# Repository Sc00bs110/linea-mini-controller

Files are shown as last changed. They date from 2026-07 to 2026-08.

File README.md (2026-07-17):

# Linea Mini Controller

An open-source ESP32-S3 touchscreen controller for the La Marzocco Linea Mini
espresso machine.

<p align="center">
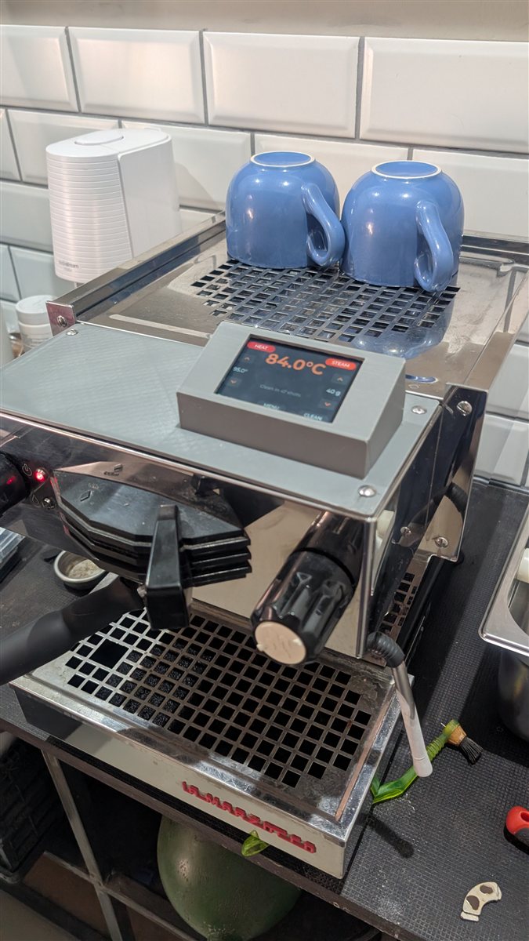
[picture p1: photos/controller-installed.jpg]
Controller in its 3D-printed housing, installed on top of a La Marzocco Linea Mini
  
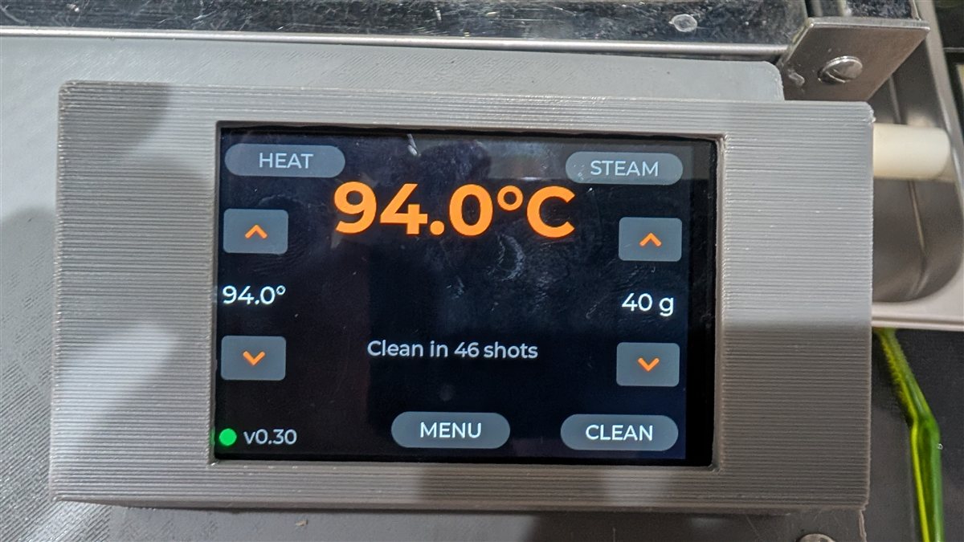
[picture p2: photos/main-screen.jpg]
Main screen close-up: boiler temperature, target temperature and brew weight, cleaning countdown, and HEAT/STEAM/MENU/CLEAN touch buttons
  
</p>

This project replaces the Linea Mini's stock control panel with a 3.5″ colour
touchscreen, adding brew-by-weight, shot timing, a cleaning-cycle reminder,
standby scheduling, Home Assistant integration, and over-the-air firmware
updates. It talks to the machine's own GICAR control board over the existing
CN11 connector using the same serial protocol the factory panel uses — **no
modification to the machine's electronics is required**, and the stock panel
can be refitted at any time.

It is a hobby project, built from a from-scratch reimplementation of the
GICAR protocol derived from sniffing the factory panel's traffic. It is not
affiliated with, endorsed by, or supported by La Marzocco.

## Features

- **Live machine display** — boiler temperature, target temperature, shot
  timer, and machine status on a 320×480 LVGL touch UI.
- **Brew-by-weight** — pairs with a Bluetooth scale (Felicita Arc or Bookoo
  Themis Ultra) and stops the shot automatically at a target weight, with a
  configurable pre-stop allowance to account for drip.
- **Shot counting that knows the difference** — pump runs shorter than
  20 seconds are treated as group-head flushes; only runs of 20 seconds or
  more count as shots.
- **Cleaning-cycle reminder** — counts down shots to the next backflush
  (interval set in the settings menu) and flags when a clean is due.
- **Standby scheduling** — daily wake and sleep times, timezone-aware.
- **Home Assistant integration** — MQTT discovery publishes boiler
  temperature, brewing state, steam and standby switches, shot counters, a
  firmware-update button, and online/availability sensors.
- **Shot history** — per-shot temperature samples logged to flash as a
  rolling window of recent shots.
- **Self-updating firmware** — the settings menu checks this repository's
  latest GitHub release and installs it from the screen: check → confirm →
  progress → reboot. A LAN-pull path (`tools/ota_pull.py`) supports fast
  iteration during development.

## Hardware

| Part | Details |
| --- | --- |
| MCU | DFRobot FireBeetle 2 ESP32-S3 (DFR0975) — ESP32-S3-WROOM-1-N16R8, 16 MB flash, 8 MB PSRAM |
| Display | DFRobot 3.5″ GDI touch display (DFR1092), 320×480, driven as an ILI9488 panel via LovyanGFX; GT911 capacitive touch over I²C |
| Machine link | UART to the machine's CN11 connector, carrying the GICAR protocol used by the stock panel |
| Scale (optional) | Felicita Arc or Bookoo Themis Ultra, via BLE |

**Wiring instructions — display, CN11 interface circuit, and power — are in
[docs/WIRING.md](docs/WIRING.md).** Deeper pin history lives in
`reference/lm_mini/` and the per-environment comments in `platformio.ini`.

An ESP32-C6 build environment (FireBeetle 2 ESP32-C6 / DFR1075) is also
defined and builds from the same source, but the S3 is the actively
maintained and deployed target.

> **CN11 wiring caveat:** the harness's TXD/RXD labels at the CN11 plug are
> crossed relative to what the wire colours and pull-up placement suggest.
> Trust decoded frames, not the labels — this cost real debugging time twice.
> If you are rewiring, verify with a loopback test at the plug before
> assuming which wire is which.

## Building from source

Requires [PlatformIO](https://platformio.org/).

```bash
cp include/secrets.h.example include/secrets.h
# edit include/secrets.h: WiFi credentials, MQTT broker, OTA password
pio run -e lm_controller_s3
```

`include/secrets.h` is gitignored and must never be committed. The
compiled-in WiFi and MQTT values only *seed* the device's flash storage on
first boot; after that the device uses its stored copies (which is how the
CI-built release binaries — compiled with blank secrets — keep your
connectivity across updates).

A pre-build hook regenerates `include/build_info.h` (git hash + build
timestamp) on every build. The human-facing version string (`FW_VERSION`,
e.g. `v0.30`) lives in `include/version.h` and is bumped on every deployed
release.

## Firmware updates

- **From the device** — Settings → "Firmware update" checks this
  repository's latest release over HTTPS and installs it if newer than the
  running version, with an on-screen confirmation step and progress readout.
- **From your LAN** — `python tools/ota_pull.py` serves a locally-built
  `firmware.bin` over HTTP and publishes an MQTT command telling the device
  to pull and flash it. This is the fast path when iterating without cutting
  a release.

Pushing a version tag (`v*`) builds the S3 firmware in GitHub Actions and
publishes a release with `firmware.bin` and a `version.json` manifest — see
`.github/workflows/release.yml`. Version history is in
[CHANGELOG.md](CHANGELOG.md).

## Repository layout

| Path | Contents |
| --- | --- |
| `src/` | Firmware: GICAR protocol driver, machine state, LVGL UI, BLE scale, MQTT/Home Assistant, OTA, shot log |
| `include/` | Headers, LVGL configuration, `version.h`, `secrets.h.example` |
| `tools/` | Build-info generator, LAN OTA server, espota fallback |
| `cad/` | OpenSCAD design and STLs for the machine-mounted display housing |
| `docs/` | Wiring instructions ([WIRING.md](docs/WIRING.md)) |
| `reference/` | Protocol captures and historical wiring notes |
| `.github/workflows/` | Tagged-release build pipeline |

## Safety

This project interfaces directly with a mains-powered heating appliance —
boiler, pump, and solenoids — via its OEM control board. Bugs in this
firmware could plausibly cause the machine to behave unexpectedly. Use at
your own risk. Not affiliated with, endorsed by, or supported by
La Marzocco.

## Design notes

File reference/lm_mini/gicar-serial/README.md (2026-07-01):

# gicar-serial — Ascaso Baby T Serial Protocol

Source: https://github.com/antondlr/gicar-serial

Reverse-engineered serial protocol for controlling an Ascaso Baby T espresso machine
via its Gicar control board and ESP32-based Bluetooth adapter.

## Key Findings

The machine uses a "Gicar 3d5 Maestro Deluxe Full Range '664' 3SSR" control board,
the same component found in professional multi-group machines. The Bluetooth daughter
board functions as a straightforward serial bridge, making the protocol accessible
to developers.

## Features

- Read and modify machine settings:
  - Power state
  - Coffee and steam temperatures
  - Shot doses and pre-infusion timing
  - Autotimer scheduling
  - Temperature display units
- Python CLI tools for reading state and adjusting parameters
- Supports direct Bluetooth connection, USB serial, or saved response files

## Relevance to La Marzocco Mini Project

Different machine (Ascaso Baby T) and different frame format (no Z/N prefix, 3-digit
address, 115200 baud) but same Gicar controller family. Key shared concepts:
- Temperature stored as value × 10
- Same checksum algorithm: sum(ASCII values, excl CS chars) mod 256
- Same register/offset addressing model

See docs/ for protocol details and memory map.
See python-poc/ for reference implementation.

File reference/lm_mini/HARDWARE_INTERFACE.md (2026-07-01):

# LilyGo T-Display-S3 — La Marzocco Mini Interface Design

## Overview

The LilyGo T-Display-S3 mounts at the front of the machine in a 3D-printed bracket.
A 4-wire cable runs from there to a small veroboard adapter mounted near CN11 inside
the machine. The adapter provides 5V power (from CN11 +12V via a buck converter) and
level-shifted serial (Gicar ASCII, 9600 8N1).

---

## CN11 Connector (machine main board)

| Pin | Signal  | Direction | Voltage |
|-----|---|---|---|
| 1 | GND | — | 0 V |
| 2 | RXD | Machine ← Gateway | 2.5V LVCMOS |
| 3 | TXD | Machine → Gateway | 2.5V LVCMOS |
| 4 | +12Vdc  | Machine → Gateway | 12 V |

> **Note:** CN11 is labelled "RS-232" but signals are empirically confirmed at
> 2.5V LVCMOS max. No level-shifter IC required.

---

## Interface Circuit

```
CN11                     Veroboard adapter              LilyGo T-Display-S3
────                     ─────────────────              ───────────────────
Pin 4 (+12V) ──────────► [XL7015 buck, adj→5V] ──────► 5V pin
Pin 1 (GND)  ──────────────────────────────────────── GND pin

                              R1 300Ω       R3 10kΩ
Pin 3 (TXD)  ─────────────────┤├──────┬─────┤├──── 3.3V
  machine transmits                   │
                                      └──────────► IO44 (UART1 RX)

                              R2 300Ω
Pin 2 (RXD)  ◄────────────────┤├───────────────── IO43 (UART1 TX)
  machine receives
```

**Firmware UART init:**
```cpp
Serial1.begin(9600, SERIAL_8N1, 44, 43, true);  // RX=IO44, TX=IO43, invert=true
```

---

## Bill of Materials

| Ref | Value | Description |
|-----|---|---|
| U1  | XL7015 module | DC-DC buck, adj 5–20V out, 0.8A, 5–80V in. Set trimmer to 5.0V before connecting. |
| R1  | 300Ω ¼W | Series resistor, CN11 TXD → IO44 |
| R2  | 300Ω ¼W | Series resistor, IO43 → CN11 RXD |
| R3  | 10kΩ ¼W | Pull-up, IO44 → 3.3V |
| — | 4-pin connector | CN11 mating connector (machine side) |
| — | 4-core cable | CN11 adapter → veroboard: +12V, GND, TXD, RXD |
| — | 4-core cable | Veroboard → LilyGo: 5V, GND, IO43, IO44 |

**Buck converter note:** The XL7015 module is rated 0.8A max. The LilyGo draws
≤500mA peak (ESP32-S3 WiFi active + display). Leave headroom by keeping the
display backlight below full brightness — cap it in firmware at ~80% (IO38 PWM).

---

## Component Notes

**R1, R2 — 300Ω series resistors**
- ESD and short-circuit protection on both signal lines
- At 9600 baud (104 µs/bit), RC time constant with ~10 pF GPIO capacitance ≈ 3 ns — negligible signal degradation
- Limits fault current to ≈10 mA if a line is shorted to GND or 3.3V

**R3 — 10kΩ pull-up on IO44**
- CN11 TXD idles high at 2.5V; ESP32-S3 VIH minimum ≈ 2.47V (0.75 × 3.3V)
- Pull-up raises the idle level to a solid 3.3V, giving reliable logic detection
- The machine's 2.5V driver easily overrides the pull-up when driving low (0V)
- Not needed on the TX line — IO43 outputs full 3.3V; machine input is tolerant

**Buck converter — initial setup**
1. Power the module from a bench supply at 12V (no load)
2. Measure output with a multimeter at the output pads
3. Adjust the trimmer pot until output reads exactly 5.0V
4. Re-measure under load (connect LilyGo, boot) — XL7015 output will sag slightly; re-trim if needed

---

## LilyGo T-Display-S3 Pin Connections

```
LilyGo T-Display-S3 (P1 header, bottom edge)
┌────────────────────────────────────┐
│  [1.9" ST7789V display]            │
│                                    │
│  ...  IO43  IO44  ...  5V  GND  ...│
│          │     │        │    │     │
│          │     │        │    └──── ◄── Veroboard GND
│          │     │        └───────── ◄── Buck 5V out
│          │     └────── R3(10kΩ)──► 3.3V
│          │             ◄── R1(300Ω) ◄── CN11 TXD (pin 3)
│          └──────────── R2(300Ω) ──► CN11 RXD (pin 2)
└────────────────────────────────────┘
```

IO17 and IO18 are used by the CST816S touch IC I2C bus (SCL/SDA) — do not use for serial.

---

## Physical Assembly

**Veroboard adapter** (small, ≤ 5×3 cm):
- XL7015 module soldered or mounted with header pins
- R1, R2, R3 inline between screw terminals or pin headers
- CN11 side: 4-pin header/screw terminal (+12V, GND, TXD, RXD)
- LilyGo side: 4-pin header/screw terminal (5V, GND, IO43, IO44)
- Mount near the existing daughterboard sub-enclosure

**Cable routing:**
- CN11 ribbon cable exits the main board sub-enclosure — splice or extend it
  to reach the veroboard adapter
- Run a 4-core cable from the veroboard adapter through the machine chassis to
  the front-mounted LilyGo; route away from mains/heating elements

**LilyGo front mount:**
- 3D-printed bracket at front of machine
- USB-C port accessible for firmware updates (or use OTA)
- IO14 button accessible or re-mapped to a front-panel button

---

## Verification Checklist

- [ ] Buck converter output trimmed to 5.00V at no load
- [ ] Buck converter output ≥ 4.85V with LilyGo powered and WiFi active
- [ ] LilyGo boots, display shows UI, WiFi connects
- [ ] `[gicar] frame` lines appear in serial monitor at 115200 baud
- [ ] Temperature readings visible on display (confirms Gicar RX working)
- [ ] Machine responds to a write command (confirms Gicar TX working)
- [ ] No heat on R1/R2/R3 after 30 min of operation

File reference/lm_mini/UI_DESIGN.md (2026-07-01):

# La Marzocco Mini Controller — UI Design

Display: LilyGo T-Display-S3, ST7789V 320×170 landscape (rotation=3, USB-left)  
Framework: LVGL 8.4 — dark theme, Montserrat fonts  
Input: CST816S capacitive touch + IO14 button (both active simultaneously)

---

## Color Palette

| Role | Hex | Usage |
|---|---|---|
| Background | `#000000` | All screens |
| Amber primary | `#D4891A` | Temperature, key values |
| Amber bright | `#F0A830` | Edit-mode values |
| Green | `#5CB85C` | Brew active, SHOT label |
| Orange | `#FF7043` | Steam active pill |
| White | `#FFFFFF` | Shot timer text, selected items |
| Grey mid | `#888888` | Status, secondary labels |
| Grey dim | `#555555` | Shots counter, hint text |
| Grey very dim | `#2A2A2A` | Hint overlays, invisible-until-lit |
| Blue highlight  | `#2878D8` | Selected settings row (20% opacity)|

---

## Typography

| Font | Size | Usage |
|---|---|---|
| Montserrat 48 | 48px | Temperature (main), elapsed time (timer)|
| Montserrat 32 | 32px | (reserved for future use) |
| Montserrat 24 | 24px | (reserved) |
| Montserrat 20 | 20px | BREWING label, SHOT label, timer temp |
| Montserrat 16 | 16px | Status, shots, settings items, hints |

---

## Screen 1 — Main

Default screen. Shows machine state at a glance.

```
┌────────────────────────────────────────────────────────────────┐ 320px
│                            ┌──────────────┐                    │
│                            │    STEAM     │  ← orange if on    │ 8px
│  93.5°C                    └──────────────┘                    │
│                                                                │ 85px (mid)
│  (amber M48)                   BREWING  ← green M20, hidden   │
│                                                                │
│                                0 shots  ← grey M16            │
│─────────────────────────────────────────────────────────────── │
│  192.168.1.113  |  Demo mode            ← grey M16            │ 148px
│  short=demo brew  long=menu  tap=settings  ← very dim         │ 164px
└────────────────────────────────────────────────────────────────┘ 170px
```

**Widgets:**
- `lbl_temp` — LEFT_MID (8, -12), M48, amber `#D4891A`
- `obj_steam` — TOP_RIGHT (-8, 8), 100×26, radius=13, bg dark → orange when active
  - `lbl_steam` — centered M16 inside pill
- `lbl_brew` — RIGHT_MID (-8, 8), M20, green, hidden when not brewing
- `lbl_shots` — RIGHT_MID (-8, 40), M16, dim grey
- `lbl_status` — BOTTOM_LEFT (8, -24), M16, grey — IP + machine state
- `lbl_hint` — BOTTOM_LEFT (8, -6), M16, very dim grey — controls hint

**Controls:**
| Input | Action |
|---|---|
| Touch (any area) | Open Settings screen |
| IO14 short press | Toggle 15s demo brew (when not connected) |
| IO14 long press  | Open Settings screen |

**Auto-transitions:**
- brew active → auto-switch to Timer screen (shot count incremented)

---

## Screen 2 — Shot Timer

Shown automatically when a brew starts. Returns to Main 3s after brew ends,
or immediately on tap.

```
┌────────────────────────────────────────────────────────────────┐
│                                                                │
│  28.5 s                          93.5°C   ← amber M20         │
│  (white M48)                                                   │
│                                  SHOT     ← green M20         │
│                                                                │
│                                         Shot #3  ← dim grey   │
└────────────────────────────────────────────────────────────────┘
```

**Widgets:**
- `lbl_shot_time` — LEFT_MID (8, -12), M48, white — `"28.5 s"` format
- `lbl_timer_temp` — RIGHT_MID (-8, -12), M20, amber — live temp
- `lbl_shot_label` — RIGHT_MID (-8, 16), M20, green, static text "SHOT"
- `lbl_timer_shots` — BOTTOM_RIGHT (-8, -6), M16, dim grey — "Shot #N"

**Controls:**
| Input | Action |
|---|---|
| Touch (any area) | Abort brew, return to Main immediately |
| IO14 (any press) | No action |

**Auto-transitions:**
- brew ends → stays on timer for 3s then auto-returns to Main

---

## Screen 3 — Settings

Entered from Main via long-press or tap. All 6 items fit within 170px.

```
┌────────────────────────────────────────────────────────────────┐ ← 26px header
│  SETTINGS       btn:short=next  long=select  tap=cycle  (dim) │
├────────────────────────────────────────────────────────────────┤
│ > Coffee temp                              93.5°C  ← selected │ 24px
│   Pre-infusion                               OFF              │ 24px
│   Steam                                      OFF              │ 24px
│   Auto-standby                               OFF              │ 24px
│   Clean cycle                                Run              │ 24px
│   Back                                                        │ 24px
└────────────────────────────────────────────────────────────────┘
```

Header: `#181818` bg, `lbl_settings_hdr` M20 grey left, hint M16 very dim right.

Each row (320×24): highlight = blue (#2878D8) at 20% opacity on selected row.
- Name label: LEFT_MID (4, 0), M16, grey → white when selected
- Value label: RIGHT_MID (-8, 0), M16, dim → amber when selected → `< val >` in bright amber when editing

**Settings items:**

| # | Name | Values | Step | Command sent on confirm |
|---|---|---|---|---|
| 0 | Coffee temp | 88.0–96.0°C | 0.5°C | `machine_set_temp()` |
| 1 | Pre-infusion  | OFF, 0.5–10.0 s | 0.5s | (TODO — register TBD) |
| 2 | Steam | ON / OFF | toggle  | `machine_set_steam()` |
| 3 | Auto-standby  | OFF, 15, 30, 60 min | cycle | (TODO — task #16) |
| 4 | Schedule | — (navigate) | — | opens Schedule List screen |
| 5 | Clean cycle | — (action) | — | opens Cleaning Cycle flow |
| 6 | Back | — (action) | — | `settings_save()` + main |

**Button controls:**
| Input | Action |
|---|---|
| Short press | Move `>` cursor to next item (wraps) |
| Long press (item) | Enter edit mode — value shows `< val >` |
| Short press (edit)| Cycle value one step |
| Long press (edit) | Confirm + save + exit edit mode |
| Long press (Back) | Save + return to Main |

**Touch controls:**
| Input | Action |
|---|---|
| Tap any value row | Immediately cycle value one step (no edit mode) |
| Tap Back row | Save + return to Main |
| Tap Clean row | Trigger clean cycle |

Both controls are live simultaneously — button and touch can be mixed freely.

---

## Navigation Flow

```
                  ┌─────────┐
      ┌──touch────►         ◄──────brew ends (3s)──┐
      │  long btn ► MAIN    │                       │
      │           │         ├────brew starts───────►TIMER
      │           └────┬────┘                       │  │
      │                │ touch / long btn            │  touch
      │                ▼                             │  (abort)
      │           SETTINGS                          │  │
      │           │       │                         │  │
      └───────────┘       └─────────────────────────┘  │
       tap Back /                                       │
       long btn on Back                                 │
                                         ◄─────────────┘
```

---

## Cleaning Cycle Flow (multi-screen guided procedure)

Entered from Settings → "Clean cycle". Seven steps, cannot be skipped.

### Step 1 — Confirmation
```
┌────────────────────────────────────────────────────────────────┐
│  CLEANING CYCLE                                                │
│                                                                │
│  Takes approx. 2 minutes.                                      │
│  Insert blind basket with cleaning powder                      │
│  and lock portafilter in place.                               │
│                                                                │
│          [Cancel]              [Start Cleaning]                │
└────────────────────────────────────────────────────────────────┘
```

### Step 2 — Paddle Prompt (cleaning)
After "Start Cleaning" is tapped: send Gicar `W00E1000182` (cleaning command).
```
┌────────────────────────────────────────────────────────────────┐
│  CLEANING CYCLE                                                │
│                                                                │
│  Move paddle to start cleaning                                 │
│                                                                │
│                    15                                          │
│              (countdown seconds)                               │
│                                                                │
│  ────────────────────────── (progress bar)                     │
└────────────────────────────────────────────────────────────────┘
```
- Monitor Gicar state bytes [28..37] for brew-active (paddle moved)
- Paddle detected → proceed to Step 3
- 15s elapsed, no paddle → show "Cleaning cancelled" + return to settings

### Step 3 — Cleaning in Progress
```
┌────────────────────────────────────────────────────────────────┐
│  CLEANING CYCLE                                                │
│                                                                │
│  Cleaning in progress...                                       │
│                                                                │
│  Cycle  3 / 10      ████████░░░░░░░░░░░░  30s                 │
│  (3 seconds ON, 3 seconds OFF per cycle)                       │
│                                                                │
└────────────────────────────────────────────────────────────────┘
```
- 10 cycles × (3s ON + 3s OFF) = ~60 seconds total
- Show cycle counter if detectable from Gicar state; otherwise show elapsed timer
- State bytes return to normal → proceed to Step 4

### Step 4 — Rinse Preparation
```
┌────────────────────────────────────────────────────────────────┐
│  CLEANING CYCLE                                                │
│                                                                │
│  Cleaning complete.                                            │
│                                                                │
│  Remove portafilter, rinse it thoroughly,                      │
│  then lock it back in place.                                   │
│                                                                │
│          [Cancel]              [Start Rinse]                   │
└────────────────────────────────────────────────────────────────┘
```

### Step 5 — Paddle Prompt (rinse)
After "Start Rinse" tapped: send `W00E1000182` again.
Same countdown and paddle-detection logic as Step 2.

### Step 6 — Rinse in Progress
Same display as Step 3, text reads "Rinsing...".  
10 cycles × (3s ON + 3s OFF).

### Step 7 — Complete
```
┌────────────────────────────────────────────────────────────────┐
│                                                                │
│                   Cleaning Complete                            │
│                                                                │
│              30 May 2026  14:23                                │
│                                                                │
│              (returns to settings in 3s)                       │
│                                                                │
└────────────────────────────────────────────────────────────────┘
```
- Record Unix timestamp to NVS: namespace `"maintenance"`, key `"last_clean_ts"`
- Display formatted date/time
- Auto-return to settings after 3 seconds

### Gicar Command
- `W00E1000182` (register 0x00E1, value 0x82, checksum 58) — confirmed via logic analyser
- Same command used for both cleaning and rinse cycles
- Machine requires user paddle movement to actually start the pump cycle

### NVS
- Namespace: `"maintenance"`, key: `"last_clean_ts"` (uint32, Unix epoch)
- Exposed in Home Assistant as sensor `last_cleaning` (ISO datetime string)

---

## Future Screens (planned)

### Screen 4 — Shot Detail (task #21)
Shows after a brew completes. Displays: shot time, yield (grams, from BLE scale),
ratio (dose:yield), temperature profile. Tap to dismiss.

### Screen 5 — Schedule (task #16)
Weekly on/off schedule editor. Grid of days × time slots.
Navigation: swipe left/right for days, tap to toggle time slots.

### Screen 6 — Scale / Brew-by-Weight Timer (tasks #19, #20, #21)

Scale: **Felicita Arc** (BLE). Replaces plain shot timer when scale is connected.

```
┌────────────────────────────────────────────────────────────────┐
│  28.5 s          ████████████░░░░░  36.2 → 40g   93.5°C       │
│  (M32, white)    (weight progress bar, green)     (M20, amber) │
│                                                                │
│  Shot #3                           1 : 2.3  (dose:yield ratio)│
└────────────────────────────────────────────────────────────────┘
```

**Auto-stop:** when live weight reaches `(target - offset)`, send brew-stop
command (`W80000001` — verify empirically, task #17). The offset compensates
for liquid still dripping after pump stops.

**Settings additions** (in settings menu):
- Brew target weight: 20–60g, step 1g (default 36g)
- Pre-stop offset: 0–8g, step 0.5g (default 3g) — stop at `target - offset`
- Scale: connect / disconnect / show status

---

## BLE Scale Integration — Architecture & Plan (tasks #19, #20, #21, #22)

**Scales on order:** Felicita Arc + Bookoo Themis Ultra  
Both must be supported simultaneously. Auto-detect on BLE scan — connect to whichever
is found first (or whichever is in range). No user configuration required.

---

### Firmware Architecture — Abstract Scale Driver

Both scales are wrapped behind a common interface so brew-by-weight, the shot
timer screen, and HA reporting never need to know which scale is connected:

```cpp
// src/scale.h

enum ScaleModel { SCALE_NONE, SCALE_FELICITA_ARC, SCALE_BOOKOO_THEMIS };

struct ScaleState {
    ScaleModel model;
    bool       connected;
    float      weight_g;   // live reading, grams
    bool       stable;     // weight stable (not changing rapidly)
};

extern ScaleState scale;

void  scale_init();                // start BLE scan task
void  scale_tare();                // send tare command to active scale
float scale_weight();              // current weight in grams (0.0 if disconnected)
bool  scale_connected();
const char* scale_name();          // "Felicita Arc" / "Bookoo Themis Ultra" / "—"
```

Internal: BLE task on core 0 scans for both device name prefixes, connects to the
first found, dispatches notifications to the correct parser, populates `scale`.
On disconnect, resumes scanning.

---

### BLE Protocol — Felicita Arc

| Item | Value |
|---|---|
| Device name prefix | `"FELICITA"` |
| Service UUID | `0xFFE0` |
| Notify characteristic | `0xFFE1` |
| Packet format | 10 bytes: `[cmd][weight_hi][weight_lo][sign][unit][...]` |
| Weight | `(byte[1] << 8 \| byte[2]) / 10.0` g; negative if `byte[3] == 1` |
| Update rate | ~10 Hz |

> Verify UUIDs and packet layout with **nRF Connect** before coding — Arc format
> differs slightly from older Felicita models.

---

### BLE Protocol — Bookoo Themis Ultra

| Item | Value |
|---|---|
| Device name prefix | `"Bookoo"` or `"BOOKOO"` |
| Service UUID | **TBD — scan with nRF Connect** |
| Notify characteristic | **TBD** |
| Packet format | **TBD** |
| Update rate | ~10 Hz (typical for espresso scales) |

> The Bookoo Themis Ultra is a newer device and its BLE protocol is less documented
> publicly. Scan with nRF Connect to capture the service/characteristic UUIDs and
> record a few notification payloads during weighing. This is needed before the
> Bookoo driver can be written.

---

### Brew-by-Weight Auto-Stop

```
During active brew, every 100 ms:
  w = scale_weight()
  if (scale_connected() && w >= (brew_target_g - prestop_offset_g)):
      gicar_write(0x8000, &stop_val, 1)   // brew stop — verify task #17
      record yield = w + drip_estimate
      mark shot as weight-stopped
      stop checking until next brew
```

**Pre-stop offset** (lag compensation):
- Espresso drips 2–4s after pump stops, adding 3–5g
- Default: 3g offset — stop pump at `target − 3g`, yield reaches ~target
- User-adjustable 0–8g in settings

---

### Shot Timer Screen — With Scale Active

```
┌────────────────────────────────────────────────────────────────┐
│  28.5 s                                            93.5°C      │
│                                                                │
│          36.2 g  ████████████████░░░░  / 40 g                 │
│          (M48 green)      (progress bar)                       │
│                                                                │
│  Shot #3                                    ratio  1 : 2.4    │
└────────────────────────────────────────────────────────────────┘
```

Without scale connected — falls back to plain elapsed timer (existing behaviour).

### Main Screen — Scale Status (right panel, below shot counter)
- Scale connected: `"36.2 g"` dim green M16
- Scanning: `"Scale..."` very dim grey M16
- Offline after timeout: nothing shown (no clutter)

---

### Settings Additions

| Item | Values | Default |
|---|---|---|
| Brew weight | 20–60 g, step 1 g | 36 g |
| Pre-stop offset | 0.0–8.0 g, step 0.5 g | 3.0 g |
| Scale status | display-only: name + RSSI or "Scanning..." | — |

---

### Home Assistant Entities (task #22)

| Entity | Type | Notes |
|---|---|---|
| `sensor.lm_scale_weight` | g | Live reading during shot |
| `sensor.lm_last_yield` | g | Yield of last completed shot |
| `sensor.lm_last_ratio` | — | Dose:yield (requires dose input) |
| `number.lm_brew_target` | g | Target brew weight |
| `number.lm_prestop_offset` | g | Pre-stop offset |
| `binary_sensor.lm_scale_connected` | — | BLE connection state |
| `sensor.lm_scale_model` | string | "Felicita Arc" / "Bookoo Themis Ultra" |

---

### Adaptive Pre-Stop Offset Algorithm

**Background — existing La Marzocco firmware:**
The gateway binary contains a `GicarAcaiaScaleMachine` class confirming scale-based
brew-stop. The NVS keys found (`scale-nm0`, `scale-nm1`, `scale-ack`) are scale
identification only — no adaptive offset keys (`scale-offset`, `scale-last-yield`,
`scale-learning-rate` etc.) were found. It is therefore **unknown** whether the
original firmware had adaptive learning; the evidence leans against it but is not
conclusive.

**Our implementation plan — adaptive pre-stop offset:**

After each completed shot where a scale was connected, record the final yield weight
(scale reading 5–10 seconds after pump stops, once dripping has slowed) and adjust
the stored offset using an exponential moving average:

```
error      = actual_yield_g - brew_target_g   // + means overshot, − means undershot
new_offset = old_offset + (error × 0.4)       // learning rate 0.4 → converges in ~4 shots
```

- Learning rate 0.4: corrects 40% of the error per shot — converges in 3–4 shots
  without overshooting
- Clamp `new_offset` to [0.0, 8.0] — safety bounds, same as manual setting
- Only update when `|error| > 0.5g` — ignore noise within half a gram
- Store in NVS (namespace `"scale"`, key `"offset"`) — survives power cycles
- Per-target tuning: offset at 36g target differs from 40g; optionally store as
  `"off_36"`, `"off_40"`, etc. (round to nearest gram) — implement if simple offset
  proves insufficiently accurate across different target weights

**Implementation order:**
1. Implement fixed offset first (done)
2. Add final-yield measurement once real scale arrives (read weight ~8s after brew ends)
3. Add NVS offset storage as part of task #15
4. Add adaptive update logic — ~20 lines, straightforward once NVS is in place

**Verification:** pull 5 shots with a consistent dose, record actual yield each time,
confirm the offset converges. If it oscillates, reduce learning rate to 0.25.

---

### Open Questions Before Coding Scale Drivers

1. **Bookoo Themis Ultra BLE:** scan with nRF Connect, record service UUID, char UUID, and 3–4 notification payloads at known weights (e.g. 10g, 20g, 30g) to reverse the encoding.
2. **Felicita Arc packet format:** confirm byte layout matches above — Arc may differ from Felicita Parallel/Brew models.
3. **Tare behaviour:** does each scale auto-tare on stable zero, or does firmware need to send an explicit tare command? Check nRF Connect for write characteristics.
4. **Brew-stop command:** verify `W80000001` empirically (task #17) before enabling auto-stop.
5. **Simultaneous scan:** confirm ESP32-S3 BLE stack handles scanning while a connection is already active (needed if user has both scales on the bench).

---

### Home Assistant integration (task #14)
No dedicated screen. HA controls are reflected in the settings screen
(same values, synced via MQTT). A small "HA" icon in the status line
indicates cloud sync active.

---

## Touch Coordinate Mapping

CST816S native: portrait X∈[0,169], Y∈[0,319]  
Display rotation=3 (landscape, USB-left) mapping:

```
display_x = SCREEN_W - 1 - raw_y   (319 - raw_y)
display_y = raw_x
```

If tap position appears mirrored, swap to Option B in `touch.cpp`:
```
display_x = raw_y
display_y = SCREEN_H - 1 - raw_x
```

---

## Pin Summary

| GPIO | Function | Notes |
|---|---|---|
| 43 | Gicar UART1 TX | CN11 → machine RXD, via 300Ω |
| 44 | Gicar UART1 RX | CN11 → machine TXD, 300Ω+10kΩ PU |
| 17 | Touch I2C SCL | CST816S on T-Display-S3 |
| 18 | Touch I2C SDA | CST816S on T-Display-S3 |
| 21 | Touch RST | Active-low reset |
| 16 | Touch INT | Interrupt (polled, not used) |
| 14 | IO14 button | Active-low, BUTTON_2 |
| 15 | LCD power enable | Must be HIGH before TFT init |
| 38 | Backlight | TFT_BL, driven HIGH |

Display parallel bus: D0-D7 = IO39-48, WR=IO8, RD=IO9, DC=IO7, CS=IO6, RST=IO5

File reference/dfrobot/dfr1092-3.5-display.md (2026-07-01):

# DFRobot 3.5" 480x320 IPS Capacitive Touch Screen (DFR1092)

Source (primary): https://wiki.dfrobot.com/dfr1092/
Also cross-checked against: https://wiki.dfrobot.com/SKU_DFR1092_3.5%22%20480%C3%97320%20IPS%20Capacitive%20Touch%20Screen
Product/store page: https://www.dfrobot.com/product-3025.html
Datasheet PDF (linked from wiki): https://dfimg.dfrobot.com/wiki/23471/DFR1092_480-320-ips-screen_datasheet_1.0.pdf
Schematic PDF (linked from wiki): https://dfimg.dfrobot.com/wiki/23471/DFR1092_480-320-ips-screen_schematics_1.0.pdf
Library (named on wiki as compatible): https://github.com/DFRobot/DFRobot_GDL

Retrieved: 2026-07-01

## HEADLINE FINDING — Driver IC is ST7365P, NOT ILI9488

**The prior iteration's assumption that this display uses an ILI9488 driver is WRONG.** The datasheet PDF that DFRobot itself links from the DFR1092 wiki page (`DFR1092_480-320-ips-screen_datasheet_1.0.pdf`) is, verbatim, the **Sitronix ST7365P** datasheet:

> "ST7365P — 320RGB x 480 dot 16.7M Color with Frame Memory — Single-Chip TFT Controller/Driver — Datasheet ... © 2013 Sitronix Technology Corporation."

This was confirmed by downloading the PDF directly and extracting its text (not just trusting a page summary) — the title page, part number, and section headers throughout the 14,700+ line document all say ST7365P/Sitronix. The panel resolution quoted in the datasheet (320 x 480) matches the DFR1092's native panel resolution exactly (DFRobot's own product description says *"It features a 320×480 IPS panel for 178° distortion-free full viewing"* — the "480×320" in the SKU/marketing name is the landscape-rotated figure).

Corroborating evidence:
- DFRobot's own `DFRobot_GDL` library (the library named as compatible with this display on the wiki) ships a driver class literally named `DFRobot_ST7365P_320x480_HW_SPI` (and a `..._DMA_SPI` DMA variant) — an exact resolution match for this panel — alongside separate classes for ILI9341/ILI9488/ST7789/ST7735S/ST7789/SSD1306 that do NOT match this panel's native resolution.
- **Likely source of the original ILI9488 assumption**: DFRobot sells a different, older, visually similar product — **DFR0669** ("Fermion: 3.5" 480x320 TFT LCD Capacitive Touchscreen with MicroSD Card Slot (Breakout)") — which genuinely IS ILI9488-driven, has the same 3.5"/480x320 spec, but uses a plain pin-header breakout (no GDI connector) and is a completely separate SKU. DFR0669 appears as a "related product" recommendation embedded in the DFR1092 wiki page's own page data, which is almost certainly what caused the mix-up. **Do not use ILI9488 init code, MADCTL values, or gamma tables for the DFR1092 — use ST7365P.**

## SKU and Physical Specs

| Parameter | Value |
|---|---|
| SKU | **DFR1092** |
| Screen size | 3.5 inches |
| Native panel resolution | 320 x 480 (portrait, per panel datasheet) — marketed as **480 x 320 (HVGA)** landscape |
| Panel type | IPS |
| Viewing angle | 178° (full view) |
| Brightness | 300 cd/m² |
| Contrast ratio | 800:1 |
| Surface treatment | Anti-fingerprint (AF) coating |
| Production process | Optical full bonding (reduces reflection, keeps out dust/moisture) |
| Effective display area | 48.96 x 73.94 mm |
| Overall dimensions | 95.0 x 54.5 x 5.7 mm |
| Mounting hole diameter | 2.0 mm |
| Mounting hole spacing | 90 x 50 mm |
| Weight | 62.6 g (with packaging) |
| Storage expansion | Built-in Micro SD card slot |

## Display Driver IC — CONFIRMED

**ST7365P** (Sitronix), a single-chip TFT controller/driver with on-chip frame memory, supporting 16.7M colors, native 320RGB x 480 dot panel. Supports both 3-line and 4-line SPI serial interface modes (datasheet sections 8.4.1 "3-Line Interface" and 8.4.2 "4-Line Interface"). The DFR1092 board is wired for **4-line SPI** (separate D/C line broken out, per the pinout below).

## Interface Type

- **SPI** (4-wire: SCLK, MOSI, MISO, CS + separate D/C and RST lines — i.e. the common "4-line" TFT SPI convention with 6 total control signals: SCK/MOSI/MISO/CS/DC/RST)
- Not parallel/RGB — this is a serial-only interface.
- Two physical connector options on the board:
  1. **GDI (Gravity Display Interface)** — DFRobot-proprietary 18-pin FPC connector, solder-free, single-cable, designed to plug directly into FireBeetle 2 boards (including the ESP32-C6 V1.2 in this project).
  2. **Standard 2.54 mm pin header** — 14 pins, for use with any generic MCU/Arduino via jumper wires.

## Touch Controller

- **Type**: Capacitive
- **Touch points**: 5-point multi-touch
- **Interface**: **I2C** — confirmed directly from the schematic (net labels `CTP_SCL`, `CTP_SDA`, `CTP_INT`, `CTP_RST` on the touch-panel FPC connector; also exposed as `SCL`/`SDA`/`INT`/`TP_R`(reset) on the 2.54 mm header and `SCL`/`SDA`/`INT`/`TCS` on the GDI connector).
- **Exact touch IC part number: NOT confirmed by a primary DFRobot source.** The wiki page, product page, datasheet, and the single-page schematic available from DFRobot all stop short of naming it (the schematic only shows a connector out to a separate touch-panel FPC/module; the touch chip itself lives on that module and isn't itemized in the documents DFRobot publishes for this SKU).
- Since the interface is I2C (not SPI), the touch IC is **not** the XPT2046 (SPI, resistive, single-touch) that `DFRobot_GDL` also supports. Of the touch drivers the library ships (`XPT2046`, `GT911`, `GT5688`), the I2C capacitive candidates are **GT911** or **GT5688** (both Goodix-family, both I2C, both multi-touch capable).
- A secondary (non-DFRobot-sourced, AI-search-synthesized) result claimed the DFR1092 specifically uses **GT911 at I2C address 0x5D**. This could not be traced to an actual DFRobot document, datasheet, or schematic text and should be treated as an **unverified lead, not a confirmed fact** — it may simply reflect GT911 being the generic, most common chip of its class rather than a DFR1092-specific citation. GT911 is the leading candidate on general-plausibility grounds (I2C, 5-point capacitive, extremely common in this display-size class, and already supported by DFRobot's own GDL library), but treat it as unconfirmed until verified against the physical unit's chip marking or direct DFRobot support confirmation.

## GDI Connector Pinout (18-pin FPC)

Order as documented on the wiki (pin 1 first):

| Pin # | FPC Label | Function |
|---|---|---|
| 1 | VCC | Power, 3.3 V |
| 2 | LCD_BL | Backlight control |
| 3 | GND | Ground |
| 4 | SCLK | SPI clock |
| 5 | MOSI | SPI host-out / slave-in |
| 6 | MISO | SPI host-in / slave-out |
| 7 | LCD_DC | Data/Command select |
| 8 | LCD_RST | Display reset |
| 9 | LCD_CS | TFT screen chip select |
| 10 | SD_CS | microSD card chip select |
| 11 | FCS | Font-library chip select |
| 12 | TCS | Touch controller chip select |
| 13 | SCL | I2C clock (touch) |
| 14 | SDA | I2C data (touch) |
| 15 | INT | Touch interrupt |
| 16 | BUSY | Tear-effect / busy signal |
| 17 | X1 | Custom/spare pin 1 |
| 18 | X2 | Custom/spare pin 2 |

This is **identical in pin order/labeling** to the GDI pinout table already documented in `reference/dfrobot/firebeetle2-esp32-c6-v1.2.md` for the FireBeetle 2 ESP32-C6 (DFR1075) board's GDI socket, including that board's GPIO mapping (SCLK=GPIO23, MOSI=GPIO22, MISO=GPIO21, LCD_DC=GPIO8, LCD_RST=GPIO14, LCD_CS=GPIO1, SD_CS=GPIO18, TCS=GPIO6, SCL=GPIO20, SDA=GPIO19, INT=GPIO7, LCD_BL=GPIO15; FCS/BUSY/X1/X2 not connected on that board). Confirmed compatible — no cross-reference conflicts found.

## Standard 2.54 mm Pin Header (14-pin alternative interface)

| Pin # | Name | Function |
|---|---|---|
| 1 | VCC | Positive power supply |
| 2 | GND | Negative power supply (ground) |
| 3 | SCLK | Clock |
| 4 | MOSI | Data, host transmits / slave receives |
| 5 | MISO | Data, host receives / slave transmits |
| 6 | SCR_CS | Screen chip select |
| 7 | RST | Reset |
| 8 | DC | Data/Command |
| 9 | BLK | Backlight (see note below) |
| 10 | SCL | Touch clock (I2C) |
| 11 | SDA | Touch data (I2C) |
| 12 | INT | Touch interrupt |
| 13 | SD_CS | SD card chip select |
| 14 | TP_R | Touch reset |

## Software / Library

- **Library name**: `DFRobot_GDL` (DFRobot's own graphics/display/touch/UI framework)
- GitHub: https://github.com/DFRobot/DFRobot_GDL
- Requires Arduino IDE 1.8.10 or later.
- Relevant driver class for this panel: **`DFRobot_ST7365P_320x480_HW_SPI`** (a DMA-SPI variant also exists for supported MCUs). Do **not** use `DFRobot_ILI9488_320x480_HW_SPI` — that class is for the unrelated DFR0669/other ILI9488 panels, not this one.
- Touch driver classes shipped in the same library: `XPT2046`, `GT911`, `GT5688` — exact class to use for DFR1092 not yet confirmed (see Touch Controller section above).
- Example sketches referenced on the wiki's "Docs" tab:
  - **basicTest** — basic drawing primitives (points, lines, shapes)
  - **gestureFont** (labeled "gettureFont" on the page, likely a typo) — UI numeric-keypad demo
  - **UI gesture** — gesture-recognition demo
- Wiki guidance quoted verbatim: *"When connecting the screen with an FPC cable, simply configure the corresponding pin numbers according to the GDL demo. Normally, only three pins need to be configured on different main controllers"* — implying most of the example sketches only require CS/DC/RST to be set per-board, with SCLK/MOSI/MISO/power fixed by the GDI connector wiring.

## Power Requirements

| Parameter | Value |
|---|---|
| Operating voltage | DC 3.3 V ~ 5 V |
| Operating current | 50 mA @ 5 V |
| Backlight control | Digital level on `LCD_BL` (GDI) / `BLK` (2.54 mm header) pin. Has a default on-state — the screen lights up even if the backlight pin is left unconnected. Per the wiki: **high level (1) = maximum brightness, low level (0) = backlight off.** The wiki only documents this as a digital high/low control; it does not state whether PWM dimming is supported. However, the schematic shows the `BLK` net driving a transistor (with base/current-limiting resistors), i.e. a transistor-switched LED backlight — this topology commonly tolerates a PWM signal on the control pin for dimming, but that is an inference from the schematic, not a documented, DFRobot-confirmed feature. Treat as digital on/off unless PWM dimming is tested and confirmed on real hardware. |

Onboard regulation (from schematic): an **ME6206A30XG** LDO regulates the incoming 3.3–5 V rail down to a local 3 V rail for the panel logic; an **TXS0108E** 8-bit bidirectional level shifter is present on the SPI/control lines (for logic-level translation between host and panel domains).

## Open Items / Flags for Firmware Bring-Up

1. **Driver IC corrected to ST7365P** — any ported firmware, `LovyanGFX`/`TFT_eSPI` config, init sequence, or MADCTL/gamma table written under the ILI9488 assumption must be replaced with ST7365P-specific configuration (or use DFRobot's own `DFRobot_GDL` / `DFRobot_ST7365P_320x480_HW_SPI` class directly, which is the officially supported path).
2. **Exact touch IC model unconfirmed** — leading candidate is GT911 (I2C, capacitive, 5-point), with GT5688 as the other library-supported alternative; an unverified secondary source claims GT911 @ 0x5D but this isn't traceable to a DFRobot primary source. Recommend checking the physical touch-panel FPC/chip marking on the real unit once it arrives, or asking DFRobot support, before finalizing touch-driver code.
3. Watch for the DFR0669 (ILI9488) vs DFR1092 (ST7365P) mix-up in any future research — they are easy to conflate because DFRobot's own site cross-links them as "related products" and both are nominally "3.5-inch 480x320 capacitive touch" panels.

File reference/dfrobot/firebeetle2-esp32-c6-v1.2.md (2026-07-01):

# DFRobot FireBeetle 2 ESP32-C6 (DFR1075)

Source: https://wiki.dfrobot.com/dfr1075/#tech_specs
(Landing page: https://wiki.dfrobot.com/dfr1075/ — "Tech Specs" tab)
Also cross-checked against: https://wiki.dfrobot.com/SKU_DFR1075_FireBeetle_2_Board_ESP32_C6
Product/store page: https://www.dfrobot.com/product-2771.html

Retrieved: 2026-07-01

## SKU / Version — CONFIRMED

- **SKU: DFR1075** — confirmed, matches project assumption.
- The wiki's spec table documents **three hardware revisions: V1.0, V1.1, V1.2**, distinguished mainly by the onboard power regulator and deep-sleep current (see Power section below). The silkscreen pin-diagram image on the wiki is explicitly labeled **"FireBeetle 2 ESP32-C6 V1.0"**, but the spec table itself lists V1.2 sleep-current data, so V1.2 is a real, documented revision — **the wiki does not call out any pinout differences between V1.0/V1.1/V1.2**, only power-related differences. Treat pinout as identical across revisions unless a schematic diff says otherwise.

## MCU / CPU

- Chip: **ESP32-C6FH4** (the "H4" suffix = 4 MB in-package flash, no PSRAM variant)
- Processor: **RISC-V single-core** (not Xtensa — this is a real architecture change vs. the ESP32-WROOM/Xtensa board this project is porting from)
- Clock: **160 MHz** main frequency
- SRAM: **512 KB**
- ROM: **320 KB**
- RTC SRAM: **16 KB**
- Flash: **4 MB** (in-package)
- **PSRAM: none.** Not mentioned anywhere on the wiki, and the "FH4" chip variant does not include PSRAM. Do not assume PSRAM is available — this differs from PSRAM-equipped ESP32 boards.
- USB: USB 2.0 CDC (native USB, used for programming/console — see UART note below)

## Wireless Radio

- WiFi: IEEE 802.11b/g/n **+ 802.11ax (WiFi 6, 20 MHz-only non-AP mode)**, 2.4 GHz only, 20/40 MHz bandwidth, Station/SoftAP/SoftAP+Station modes, TX/RX A-MPDU & A-MSDU aggregation
- Bluetooth: **Bluetooth 5, Bluetooth mesh**, 125 Kbps–2 Mbps
- IEEE 802.15.4 radio (2.4 GHz, 250 Kbps): supports **Thread 1.3** and **Zigbee 3.0** — board can act as Thread border router / Matter gateway / Zigbee bridge

## Peripheral Counts (per wiki "Ports" table)

- Digital I/O: **19**
- LED PWM: 6 channels
- **SPI: x1** — CONFIRMED, only one SPI peripheral is broken out on this board (see SPI section)
- UART: x3 total (includes 1 LP-UART); only one full UART (GPIO16/17) is broken out to a labeled header pin pair
- I2C: x2 (includes 1 LP-I2C)
- I2S: x1
- IR transceiver: 2 TX / 2 RX channels
- ADC: 1x 12-bit SAR ADC, 7 channels
- DMA: 3 TX / 3 RX channels

## Power

| Parameter | Value |
|---|---|
| Operating voltage | 3.3 V |
| Type-C input voltage | 5 V DC |
| VIN pin input | 5 V DC or 5 V solar panel |
| Max charging current | 0.5 A |
| Deep-sleep current (battery powered) | V1.0: 16 µA; **V1.2: 36 µA** |
| Operating temp | -10 to 60 °C |
| Dimensions | 25.4 x 60 mm (1 x 2.36") |

- Onboard regulator: **HM6245** 3.3 V low-power LDO (V1.0) or **TPS62A02DRLR** 3.3 V DC-DC converter (V1.1). The regulator used on V1.2 specifically is not called out separately on this page.
- Solar charging: **CN3165** solar power management chip (MPPT) — VIN pin doubles as solar panel input.
- **BAT** pin: direct Li-ion/Li-Po battery connector (JST-style on-board connector, not just a header pin), with onboard charge management.
- **IO0** is dual-purposed as the **battery voltage detection pin** (analog read of battery voltage) — note this if IO0/GPIO0 is needed for anything else.
- Charging LED indicator: off = not powered/fully charged, on = charging.

## Strapping / Boot / Reserved Pins

From the pin diagram, these GPIOs carry boot-strapping or JTAG functions and need care:

| GPIO | Alt. functions | Notes |
|---|---|---|
| GPIO4 | A3, LP_RX, ADC1_4, **MTMS** (JTAG) | Strapping pin on ESP32-C6 |
| GPIO5 | A4, LP_TX, ADC1_5, **MTDI** (JTAG) | Strapping pin on ESP32-C6 |
| GPIO6 | D12, LP_SDA, ADC1_6, **MTCK** (JTAG) | Strapping pin on ESP32-C6 |
| GPIO7 | D11, LP_SCL, **MTDO** (JTAG) | Strapping pin on ESP32-C6 |
| GPIO8 | D2 | Strapping pin on ESP32-C6 (general knowledge; not separately flagged on wiki page) |
| GPIO9 | D9 / **BOOT** | Labeled directly on silkscreen as the BOOT button pin — classic ESP32-C6 boot-mode strapping pin |
| GPIO15 | D13 | Onboard LED pin |
| GPIO0 | — | Repurposed as **battery voltage detection** input |

**GPIO16 and GPIO17 — SAFE for UART.** They are explicitly silkscreened and diagrammed as **"16/TX"** and **"17/RX"** — i.e., DFRobot has broken these out specifically as the board's main UART pin pair, with no JTAG, ADC, LP-peripheral, or strapping function listed for either pin. They carry no strapping role on ESP32-C6. This confirms the prior iteration's GPIO16/17 UART TX/RX reservation for the espresso-machine control-board link **carries over cleanly to this board** — no conflict found.

One caveat worth flagging for firmware bring-up (not a wiki-documented fact, but standard ESP32-C6 behavior worth verifying in code): GPIO16/17 are the chip's **default UART0** pins, which some ESP-IDF configurations use for the boot-log/console. Since this board also exposes native USB (USB-Serial-JTAG via the Type-C port) for programming and console, the console should be configured to use the native USB channel instead of UART0, freeing GPIO16/17 exclusively for the espresso-machine link. Recommend confirming `CONFIG_ESP_CONSOLE_USB_SERIAL_JTAG` (or PlatformIO/Arduino equivalent) is selected instead of UART0 console during firmware setup.

## SPI Bus — CONFIRMED single SPI

The wiki's port table lists **"SPI x1"**. The only SPI signals broken out to headers are:

- GPIO23 = SCK (also silkscreened as SDIO DAT3)
- GPIO22 = MOSI (also SDIO DAT2)
- GPIO21 = MISO (also SDIO DAT1)

These same three pins are also the ones wired straight to the **GDI connector's SCLK/MOSI/MISO** (see below), so the one available SPI bus is the same bus the GDI display will use. There is no second independent SPI bus broken out on this board — the project note that "only one usable SPI peripheral" exists is **confirmed accurate**. Any other SPI-attached peripheral will need to share this bus (with its own CS line) or bit-bang a software SPI on spare GPIOs.

## Full Pinout (both header rows)

Left header (top → bottom):

| Silkscreen | GPIO | Notes |
|---|---|---|
| RST | — | Reset button |
| 3V3 | — | |
| GND | — | |
| DAT3 / SCK | GPIO23 | SPI SCK / SDIO DAT3 |
| DAT2 / MOSI | GPIO22 | SPI MOSI / SDIO DAT2 |
| DAT1 / MISO | GPIO21 | SPI MISO / SDIO DAT1 |
| DAT0 / SCL | GPIO20 | I2C SCL / SDIO DAT0 |
| CLK / SDA | GPIO19 | I2C SDA / SDIO CLK |
| D9 | GPIO9 | **BOOT strapping pin**, boot button |
| CMD / D7 | GPIO18 | SDIO CMD |
| ADC1_1 / D6 | GPIO1 | ADC1 channel 1 |
| NC | — | |
| D3 | GPIO14 | |
| D2 | GPIO8 | Strapping pin (ESP32-C6) |
| TX | GPIO16 | **UART0 TX** |
| RX | GPIO17 | **UART0 RX** |

Right header (top → bottom):

| Silkscreen | GPIO | Notes |
|---|---|---|
| VIN | — | 5 V in (USB/solar) |
| 3V3 | — | |
| GND | — | |
| SCL | GPIO20 | (mirrors left-header GPIO20) |
| SDA | GPIO19 | (mirrors left-header GPIO19) |
| A4 / LP_TX | GPIO5 | ADC1_5, LP-UART TX, **MTDI (JTAG)**, strapping |
| A3 / LP_RX | GPIO4 | ADC1_4, LP-UART RX, **MTMS (JTAG)**, strapping |
| A2 | GPIO3 | ADC1_3 |
| A1 | GPIO2 | ADC1_2 |
| NC | — | |
| D13 | GPIO15 | Onboard LED |
| D12 / LP_SDA | GPIO6 | ADC1_6, LP-I2C SDA, **MTCK (JTAG)**, strapping |
| D11 / LP_SCL | GPIO7 | LP-I2C SCL, **MTDO (JTAG)**, strapping |
| NC | — | |

(GPIO20/GPIO19 physically appear on both headers — same nets, broken out twice.)

## GDI (Gravity Display Interface) Connector — 18-pin FPC

This is the connector the DFR1092 3.5" GDI display will plug into. Pin order as documented on the wiki:

| FPC Pin # (order) | FPC Label | Board Pin / GPIO | Function |
|---|---|---|---|
| 1 | VCC | 3V3 | 3.3 V power |
| 2 | LCD_BL | GPIO15 / D13 | Backlight |
| 3 | GND | GND | Ground |
| 4 | SCLK | GPIO23 / SCK | SPI clock |
| 5 | MOSI | GPIO22 / MOSI | SPI host-out |
| 6 | MISO | GPIO21 / MISO | SPI host-in |
| 7 | LCD_DC | GPIO8 / D2 | Data/command select |
| 8 | LCD_RST | GPIO14 / D3 | Display reset |
| 9 | LCD_CS | GPIO1 / D6 | TFT chip select |
| 10 | SD_CS | GPIO18 / D7 | microSD chip select (if display has SD slot) |
| 11 | FCS | NC | Font-library chip select (not connected on this board) |
| 12 | TCS | GPIO6 / D12 | Touch controller chip select |
| 13 | SCL | GPIO20 | I2C clock (touch) |
| 14 | SDA | GPIO19 | I2C data (touch) |
| 15 | INT | GPIO7 / D1 | Touch interrupt |
| 16 | BUSY | NC | Tearing/busy signal — not connected on this board |
| 17 | X1 | NC | Custom/spare pin 1 — not connected |
| 18 | X2 | NC | Custom/spare pin 2 — not connected |

Wiki note: "When using FPC to connect the screen, please configure the corresponding pin numbers according to the GDL demo. Normally, only three pins need to be configured on different main controllers" (implies most DFRobot_GDL example code only needs CS/DC/RST configured per-board; SCLK/MOSI/MISO/power are fixed by the connector).

Displays explicitly listed as GDI-compatible on this wiki page: 1.54" 240x240 IPS, 1.8" 128x160 IPS TFT, 2.0" 320x240 IPS, 2.8" 320x240 IPS resistive touch, **3.5" 480x320 IPS capacitive touch** (this is the DFR1092 family), and a 1.51" OLED transparent display.

## Downloadable Resources (linked from wiki page, not yet fetched into this repo)

- Dimension drawing, Schematics, STP files, Datasheet — available via "Downloadable Resources" links on https://wiki.dfrobot.com/dfr1075/
- ESP32-C6FH4 chip datasheet linked from the board's "Pin & Component Description" table
- HM6245 / TPS62A02DRLR / CN3165 datasheets also linked individually from the same table

## Flags / Things That Surprised Me

1. **No PSRAM** on this chip variant (ESP32-C6FH4) — if the ported firmware assumed PSRAM was available (common on ESP32-WROOM boards with 8MB PSRAM variants), that assumption needs to be dropped or the flash-only 512KB SRAM budget needs to be checked against firmware RAM usage.
2. GPIO4/5/6/7 double as **JTAG** signals (MTMS/MTDI/MTCK/MTDO) — if this project ever wants to wire up hardware JTAG debugging, those four pins are already spoken for by other functions (LP-UART, LP-I2C, ADC) per the pinout above.
3. GPIO16/17 (UART for the espresso control board) check out clean — no strapping/JTAG/ADC conflicts — but double-check the console-output config so ESP-IDF doesn't also try to print boot logs over the same UART0 pins (native USB console is available as the alternative).
4. Single SPI bus is confirmed, and it is the same bus already wired to the GDI connector (SCLK=23/MOSI=22/MISO=21) — any additional SPI device will have to share this bus via a CS line rather than get an independent bus.

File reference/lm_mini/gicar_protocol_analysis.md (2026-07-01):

# Gicar Controller Protocol & Register Deep-Dive Analysis
**Linea Mini IoT Gateway & Gicar Controller Reverse Engineering**

This document details the findings from a comprehensive reverse engineering analysis of the Linea Mini IoT firmware binaries:
- [lm_gateway_backup.bin](file:///C:/Users/johnb/Documents/antigravity/LaMarzocco_Mini/firmware/lm_gateway_backup.bin) (4MB ESP32 Gateway firmware)
- [lm_storage.bin](file:///C:/Users/johnb/Documents/antigravity/LaMarzocco_Mini/firmware/lm_storage.bin) (4MB LittleFS image containing storage files)
- [machine.bin](file:///C:/Users/johnb/Documents/antigravity/LaMarzocco_Mini/firmware/storage/machine.bin) (28KB AVR ATmega32 microcontroller binary extracted from storage)

These findings compare the existing [GICAR_REGISTER_MAP.md](file:///C:/Users/johnb/Documents/antigravity/LaMarzocco_Mini/GICAR_REGISTER_MAP.md) with our static analysis of the gateway code and the microcontroller assembly.

---

## 1. Overview of the Firmware Stack

Our analysis of the binaries shows that the IoT system consists of two main processing units:
1. **The IoT Gateway (ESP32)**: Running the application stack compiled in `lm_gateway_backup.bin`. It communicates with the cloud (MQTT/HTTPS) and Bluetooth scales (Acaia Lunar), and acts as the serial master for the Gicar board.
2. **The Gicar Controller (ATmega32)**: Running the low-level machine safety, boiler control, and logic loops. It acts as a serial slave, responding to commands sent by the gateway. The firmware is stored in the Gateway's LittleFS filesystem (`lm_storage.bin`) as `machine.bin` so that the gateway can flash it during OTA updates.

---

## 2. Newly Discovered Gicar Command Protocols

The standard Gicar protocol uses `'R'` (Read) and `'W'` (Write) commands. However, disassembly of the microcontroller's UART receiver packet parser (`machine.bin` offset `0x27CA`) reveals three **new command characters** that were previously undocumented:

| Command Char | ASCII (Hex) | Purpose / Description | Expected Response |
|:---:|:---:|---|---|
| **`H`** | `0x48` | **Serial Handshake / Echo Check**: Verifies serial connection and latency. | `Z[N]OK[CS]` |
| **`X`** | `0x58` | **Model Info & Version Query**: Requests firmware identifier strings. | `Z[N]X00000001[CS]` |
| **`S`** | `0x53` | **Status / Sensor Test Toggle**: Triggers internal self-tests (sets SRAM `0x0064` to `0x0A`). | Depends on sensor state |

### Handshake Protocol Example:
- **Gateway Sends**: `H50` (where `50` is the checksum of `'H'`)
- **Gicar Responds**: `Z0OK4B` (where `4B` is the checksum of `'O'` + `'K'`)

---

## 3. Newly Discovered Gicar Registers

By tracing the register mapping functions in the gateway's [GicarCmdService](file:///C:/Users/johnb/Documents/antigravity/LaMarzocco_Mini/firmware/disasm_full.txt) and the AVR address resolver `0x23D8` in `machine.bin`, we identified a set of missing registers.

### A. Factory Test Mode Relays (`0x8000` - `0x8007`)
In `GICAR_REGISTER_MAP.md`, these were speculatively marked as "Advanced group/boiler control". Disassembly of the gateway's `GicarCmdService` reveals that these are **Factory Test Mode Relays** used for diagnostics. 

> [!WARNING]
> These registers only accept write commands if the Gicar controller is put into **Test Mode** first (otherwise, the controller responds with `"Machine Not in test mode"`).

| Address | R/W | Length (Bytes) | Command Example | Target Telemetry / Relay Activated |
|:---:|:---:|:---:|---|---|
| **`0x8000`** | W | 1 | `W8000000101` | Pump Relay & Pre-Infusion (`TEST PRE_INF`) |
| **`0x8002`** | W | 1 | `W8002000101` | Coffee Boiler Heating Element Relay (`TEST R_CAFF`) |
| **`0x8003`** | W | 1 | `W8003000101` | Steam Boiler Heating Element Relay (`TEST R_VAPO`) |
| **`0x8004`** | W | 1 | `W8004000101` | Coffee Solenoid 3-Way Valve (`TEST EV_CAFF`) |
| **`0x8005`** | W | 1 | `W8005000101` | Water Refill Solenoid Valve (`TEST EV_CARICO`) |
| **`0x8007`** | W | 1 | `W8007000101` | Display LEDs Test (`DISPLAY_TEST` / `TEST LED`) |

### B. Steam Boiler Offset Register (`0x00FD`)
- **Address**: `0x00FD` (R/W, 1 byte)
- **Function**: Writes a 1-byte temperature offset value (`steam_offset`) to calibrate the steam boiler temp readout.
- **Gateway string**: `[0;32mI (%s) %s: Stean Offset : %d` (with a typo `"Stean"` in ESP32 logs).

### C. Telemetry Data Register (`0x401C`)
- **Address**: `0x401C` (R, 4 bytes)
- **Function**: Polled by the gateway during active operations. Maps to scale weight status, flow telemetry, or error logging buffers.

### D. Block Read Commands for Pre-Infusion Settings
The Gicar controller groups pre-infusion timings in large blocks to reduce serial transmission overhead. The gateway uses the following block reads instead of single register lookups:

| Address | R/W | Length (Bytes) | Memory Buffer Layout |
|:---:|:---:|:---:|---|
| **`0x0101`** | R/W | 16 (`0x0010`) | **Group 1 pre-infusion wet/ON times** (5 buttons + padding). |
| **`0x0111`** | R/W | 37 (`0x0025`) | **Group 1 pre-infusion hold/OFF times** (5 buttons + padding). |
| **`0x0136`** | R/W | 26 (`0x001A`) | Group 2 pre-infusion wet/ON times (unused on single-group Mini). |
| **`0x0150`** | R/W | 37 (`0x0025`) | Group 2 pre-infusion hold/OFF times (unused on single-group Mini). |
| **`0x0100`** | R/W | 1 (`0x0001`)  | Pre-infusion Mode configuration state. |

---

## 4. Complete Gicar Register Map Comparison

The table below maps all registers identified across the ESP32 Gateway and the AVR Controller, highlighting what was previously missing:

| Register Address | Operation | Size (Bytes) | Status in `GICAR_REGISTER_MAP.md` | Actual Purpose / Context |
|---|:---:|:---:|---|---|
| **`0x0000`** | R/W | 1 | Partially Documented | Machine identity and status flags |
| **`0x0002`** | W | 1 | **Missing** | Refill / configuration write command |
| **`0x0006`** | R | 1 | Documented | Machine configuration byte |
| **`0x0007`** | W | 2 | Documented | Coffee boiler temperature setpoint (High Byte) |
| **`0x0008`** | W | 1 | **Missing** | Coffee boiler temperature setpoint (Low Byte) |
| **`0x0009`** | W | 2 | Documented | Steam/Secondary boiler temperature setpoint |
| **`0x0020`** | R | 44 | Documented | EEPROM / Configuration parameter block dump |
| **`0x0050`** | R | 24 | Documented | Real-time sensor and telemetry status block |
| **`0x0058`** | W | 1 | Documented | Machine soft-reboot trigger |
| **`0x0059`** | W | 2 | Documented | Purpose unknown |
| **`0x00E1`** | W | 1 | Documented | Operating mode register (Refill, Steam, Cleaning) |
| **`0x00E2`** | R | 1 | Documented | Post-mode command initialization read |
| **`0x00FD`** | W | 1 | **Missing** | Steam boiler temperature calibration offset (`steam_offset`) |
| **`0x0100`** | R/W | 1 | **Missing** | Pre-infusion status flag |
| **`0x0101`** | R/W | 16 | **Missing (polled)** | Group 1 pre-infusion wet/ON block |
| **`0x0111`** | R/W | 37 | **Missing (polled)** | Group 1 pre-infusion hold/OFF block |
| **`0x0136`** | R/W | 26 | **Missing (polled)** | Group 2 pre-infusion wet/ON block |
| **`0x0150`** | R/W | 37 | **Missing (polled)** | Group 2 pre-infusion hold/OFF block |
| **`0x0300`** | R/W | 7 | Documented | Mode configuration block |
| **`0x0310`** | R/W | 29 | Documented (Write missing) | Calibration and diagnostics buffer |
| **`0x0400`** | W | 3 or 7 | **Missing** | Firmware flash utility controller interface |
| **`0x0406`** | W | 1 | Documented | Machine Standby Mode trigger |
| **`0x0410`** | R/W | 29 | Documented (Write missing) | Calibrations block |
| **`0x4000`** | R | 35 | Documented | Machine state poll (Z6 temperature stream) |
| **`0x4001`** | R | 1 | Documented | Coffee boiler heating state |
| **`0x4002`** | R | 1 | Documented | Steam boiler heating state |
| **`0x4003`** | R | 12 | Documented | Shot timer and telemetry values |
| **`0x4010`** | R | 1 | Documented | Real-time water refill probe status |
| **`0x401C`** | R | 4 | **Missing** | Telemetry logs (shot diagnostics, weight status) |
| **`0x8000`** | W | 1 | Documented (Incorrect) | Test mode: Pump & Pre-infusion relay |
| **`0x8002`** | W | 1 | Documented (Incorrect) | Test mode: Coffee boiler relay |
| **`0x8003`** | W | 1 | Documented (Incorrect) | Test mode: Steam boiler relay |
| **`0x8004`** | W | 1 | Documented (Incorrect) | Test mode: Coffee solenoid valve |
| **`0x8005`** | W | 1 | Documented (Incorrect) | Test mode: Refill solenoid valve |
| **`0x8007`** | W | 1 | Documented (Incorrect) | Test mode: Display/LED test |

---

## 5. Handshake & Bootloader Flashing Protocols

Deep analysis of the gateway firmware binary (`lm_gateway_backup.bin`) and Gicar microcontroller firmware (`machine.bin`) reveals a dual-mode communication handshake scheme. The gateway interfaces with the Gicar board in two separate states: **Application Mode** (normal operation) and **Bootloader Mode** (firmware updates).

### A. Application Mode Handshake (Probe Connection)
To establish and verify a connection on boot or reboot, the gateway queries the machine's running state using the **Application Probe** command:

- **Probe Request (Gateway -> Gicar)**: `X00000000D8`
  - Command: `'X'` (`0x58`)
  - Address/Length bytes: `00000000`
  - Checksum: `D8` (computed as `(0x58 + 0x30 * 8) % 256 = 0xD8`)
- **Probe Response (Gicar -> Gateway)**: `Z[seq]X00000001[2-byte status][CS]` (15 bytes total)
  - Prefix: `Z[seq]`
  - Command: `'X'`
  - Status Payload: `00000001` (indicates running in application mode)
  - Telemetry Data: 2 bytes of sensor data
  - Checksum: 2 ASCII hex characters

Once the gateway parses a valid 15-byte `ZX00000001` frame, it transitions the machine state to `connected = true` and starts regular telemetry register polling (`R40000023` every 100ms).

### B. Bootloader Mode & Flashing Handshakes
During firmware recovery or OTA updates, the gateway forces the Gicar board to reboot into its internal bootloader using the following sequence:

1. **Enter Bootloader Command**: The gateway sends `X00000002DA` (checksum `DA`).
2. **Bootloader Sync Frame**: Upon rebooting into the bootloader, the Gicar board continuously broadcasts the sync packet `HRYF3` over serial (`'H' + 'R' + 'Y' = 0x48 + 0x52 + 0x59 = 0xF3` checksum).
3. **Bootloader Handshake**: The gateway responds to the sync frame with a bootloader handshake `H00000000C8`. The Gicar board acknowledges with `HOKE2` (`'H' + 'O' + 'K' = 0xE2` checksum).
4. **Firmware Header Transmission**: The gateway initiates the transfer by sending `H0000` + `[4-digit hex firmware size]` + checksum.
5. **Firmware Chunk Acknowledgment**: The gateway writes binary chunks, and after each chunk, the Gicar board responds with `#OKBD` (`'#' + 'O' + 'K' = 0xBD` checksum).
6. **Exit Bootloader Command**: Once transmission completes, the gateway reboots the Gicar board back to application mode by sending `X00000001D9` (checksum `D9`).

---

## 6. Microcontroller Memory Map Analysis

In `machine.bin`, the Gicar address lookup is optimized by matching offset blocks. The registers `0x00AE` through `0x00C9` are placed in a continuous sequence inside SRAM (starting at `0x00AE`) and directly mirror EEPROM locations `0x00` through `0x1B` (word-aligned):

```mermaid
graph TD
    A[Gicar Serial Cmd: W0101] --> B[Z Register arithmetic: Z = 0x0108 + offset]
    B --> C[Offset Checked via SUBI/SBCI]
    C --> D[EEPROM Mapping]
    D -->|Offset 0x20| E[SRAM 0x00AE: Group 1 wet/ON time]
    D -->|Offset 0x21| F[SRAM 0x00AF: Group 1 hold/OFF time]
```

When a write occurs to these settings, the microcontroller:
1. Receives the data byte in the UART RX loop.
2. Writes it to the corresponding SRAM address in the `0x00AE - 0x00C9` block.
3. Invokes the EEPROM writer function [0x1908](file:///C:/Users/johnb/Documents/antigravity/LaMarzocco_Mini/firmware/disasm_full.txt#L3223) passing the EEPROM offset, ensuring configurations persist across power cycles.

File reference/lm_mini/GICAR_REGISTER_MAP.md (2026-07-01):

# Gicar Register Map — La Marzocco Linea Mini

Sources: logic analyser captures (PulseView .sr files), gateway firmware binary (`lm_gateway_backup.bin`),
Android APK analysis (`La Marzocco Home_2.1.3` and `3.1.6`), machine.bin AVR disassembly.

---

## Protocol Format

```
Write:    W[AAAA][LLLL][DATA][CS]
Read req: R[AAAA][LLLL][CS]
Response: Z[N][R/W][AAAA][DATA][CS]   (success)
Response: Z[N][R/W][AAAA]KO[CS]       (error)
```

- All fields are ASCII-encoded hex (uppercase)
- AAAA = 4-char register address
- LLLL = 4-char length in bytes
- CS   = 2-char checksum: `sum(all bytes from R/W char through end of DATA) mod 256`
- **Commands (gateway→machine) carry NO Z[N] prefix** — confirmed 2026-06-12 by decoding
  the D1 gateway-TX channel of the dual-channel captures: raw `R40000023DB`,
  `W00E100018258`, etc. Z[N] framing appears only on machine→gateway frames,
  where it is excluded from the checksum.
- Gateway polls `R40000023DB` every **~760 ms** (the 10 Hz 54-byte stream is
  autonomous, not 1:1 poll replies)
- Baud: 9600 8N1, 3.3V TTL, **inverted polarity** on CN11

Checksum function:
```python
def gicar_cs(payload: str) -> str:
    return f"{sum(payload.encode()) & 0xFF:02X}"
# e.g. gicar_cs("W00E10001" + "81") -> "57"
```

---

## Confirmed Registers (verified from logic analyser captures)

| Address | R/W | Len | Full Command Example | Function |
|---|-----|-----|---|---|
| 0x4000  | R | 35  | `R40000023DB` | Machine state poll (main Z6 stream) |
| 0x0007  | W | 2 | `W0007000203A2B6` | Coffee boiler temp setpoint — 16-bit big-endian, 0.1°C units. 0x03A2=930=93.0°C. Range: 88–96°C |
| 0x00E1  | W | 1 | `W00E100018157` | Mode register — see values below |
| 0x0300  | R/W | 7 | `W030000070F36100516...` | Mode config block — read then write-back after mode changes |
| 0x0000  | R | — | part of init sequence | Read after mode commands (post-command init) |
| 0x0020  | R | — | part of init sequence | Read after mode commands |
| 0x0310  | R | — | part of init sequence | Read after mode commands |
| 0x00E2  | R | — | part of init sequence | Read after mode commands |

### 0x00E1 Mode Register Values

| Write Command | Value | Function | CS verified |
|---|---|---|---|
| `W00E100018157` | 0x81  | Steam boiler ON | ✓ |
| `W00E10001014F` | 0x01  | Steam boiler OFF  | ✓ |
| `W00E100018258` | 0x82  | Start cleaning cycle | ✓ |

Bit field (speculative): bit7=active command, bit1=cleaning, bit0=steam

### Post-Command Init Sequence
After writing to 0x00E1 (steam ON, cleaning): gateway reads 0x0000 → 0x0020 → 0x0310 → 0x0300 → 0x00E2,
then writes 0x0300 back unchanged. Steam OFF skips this sequence entirely.

---

## High-Confidence Registers (extracted from firmware binary)

| Address | R/W | Len | Command / Template | Function |
|---|-----|-----|---|---|
| 0x000B  | W | 1 | `W000B000100/101/102` | **Pre-infusion mode** — 0x00=Disabled, 0x01=TypeA, 0x02=TypeB |
| 0x0101  | W | 1 | `W01010010` (template) | **Pre-infusion wet/ON time** — default 0x10. Unit: TBD (likely seconds or deciseconds) |
| 0x0111  | W | 1 | `W01110025` (template) | **Pre-infusion hold/OFF time** — default 0x25. Unit: TBD |
| 0x0406  | W | 1 | `W04060001` | **Machine standby on/off** — 0x01 = on (candidate, verify empirically) |
| 0x0009  | W | 2 | `W00090002` (template) | Boiler 2 temp target — multi-model gateway; likely unused on Mini |
| 0x0059  | W | 2 | `W00590002` (template) | Purpose unknown on Mini |
| 0x0058  | W | 1 | `W0058000101` | Machine reboot trigger (part of reboot sequence, not normal use) |
| 0x001F  | W | 1 | `W001F000101` | Part of machine reboot sequence |
| 0x8000  | W | 1 | `W80000001` | Brew stop — **unconfirmed**, verify empirically during active shot |

### Pre-Infusion Details
- Gateway config key names: `enable_prebrewing`, `ton_prebrewing_k1..k4`, `toff_prebrewing_k1..k4`
- App-level names: `TON_PREBREWING_K1` (wetTimeMs), `TOFF_PREBREWING_K1` (holdTimeMs)
- Three modes: Disabled / TypeA (standard pre-infusion) / TypeB
- Default timing values: 0x10=16, 0x25=37, 0x1A=26 raw units
- Registers 0x0136 (default 0x1A) and 0x0150 (default 0x25) likely cover K2–K4 groups (irrelevant on single-group Mini)
- **Action**: once board running, write 0x05 to 0x0101, observe pre-brew duration to determine unit

### Standby Details
- Gateway stores `standby_mode` and `stby_timer` in NVS (not sent to machine every boot)
- `stby_timer` = inactivity timeout (minutes) — likely handled by gateway timer, not a machine register
- 0x0406 write with 0x01 is the strongest candidate for machine wake/standby toggle

---

## Register Map (from firmware binary string table)

| Address | Read Command | Write Command | Notes |
|---|---|---|---|
| 0x0000  | `R00000001` | `W00000001` | Machine identity/status probe  |
| 0x0006  | `R00060001` | — | |
| 0x0007  | — | `W00070002` + data | **Coffee temp setpoint** (CONFIRMED) |
| 0x0009  | — | `W00090002` + data | Boiler 2 temp (multi-model) |
| 0x000B  | — | `W000B0001` + val  | **Pre-infusion mode** (0/1/2)  |
| 0x001F  | — | `W001F000101` | Reboot sequence |
| 0x0020  | `R0020002C` | — | 44-byte read |
| 0x0050  | `R00500018` | — | 24-byte read |
| 0x0058  | — | `W0058000101` | Machine reboot trigger |
| 0x0059  | — | `W00590002` + data | Unknown on Mini |
| 0x00E1  | — | `W00E10001` + val  | **Mode register** (CONFIRMED)  |
| 0x00E2  | `R00E20001` | — | Post-command init read |
| 0x0100  | `R01000001` | `W010000015A` / `W0100000100` | |
| 0x0101  | — | `W01010001` + val  | **Pre-infusion wet/ON time** |
| 0x0111  | — | `W01110001` + val  | **Pre-infusion hold/OFF time** |
| 0x0136  | — | `W01360001` + val  | Pre-infusion timing K2 (unused on Mini) |
| 0x0150  | — | `W01500001` + val  | Pre-infusion timing K2 (unused on Mini) |
| 0x0300  | — | `W03000007` | Mode config block write-back |
| 0x0310  | `R0310001D` | `W03100001` | 29-byte read |
| 0x0400  | — | `W04000003` / `W04000007` | Boot/mode control |
| 0x0406  | — | `W04060001` | **Standby on/off** (candidate) |
| 0x0410  | `R0410001D` | `W04100001` | 29-byte read |
| 0x4000  | `R40000023DB`  | — | **Machine state poll** (CONFIRMED) — 35-byte Z6 stream frame |
| 0x4001  | `R40010001` | — | Realtime data |
| 0x4002  | `R40020001` | — | Realtime data |
| 0x4003  | `R4003000C` | — | 12-byte realtime data |
| 0x4010  | `R40100001` | — | Realtime data |
| 0x8000  | — | `W80000001` | Brew stop (unconfirmed) |
| 0x8002–0x8007 | — | `W800x0001` | Advanced group/boiler control  |

---

## Machine Stream Frame (54 bytes, ~10 Hz, autonomous)

The machine broadcasts 54-byte frames at ~10 Hz regardless of polling.

| Byte offset | Content | Notes |
|---|---|---|
| 0 | 'Z' (0x5A) | Frame start |
| 1 | 0x36 = 54 | Total frame length (NOT a seq echo — gateway TX has no seq) |
| 2–5 | '0000' (ASCII) | Register address 0x0000 |
| 28–37 | State bytes | **All non-zero even at IDLE** (`9A AA 9A 8A 82 8A 82 82 82 82` in idle + cleaning captures). Idle-vs-brewing diff NOT yet decoded. |
| 38–39 | Frame type indicator | 0x9A09 = temperature frame (else rolling counter) |
| 40–47 | Coffee boiler temp (ASCII hex) | `int(frame[40:48], 16) / 10.0` °C |
| 48–51 | Steam temp (ASCII hex) | Always '0000' — pressurestat only  |

Brew detection: **payload[17] = 0x01 while brewing, 0x00 at idle** — confirmed from live
shot capture (2026-06-14). Lever pull sets the bit; shot completion clears it.
Temperature drops ~5°C during a 36s shot (94→89°C) as expected.

---

## Machine Identity

- Type: LINEA (code 3), model tag `NEWMINIL` in AVR firmware
- Serial: Sn2011010551
- Firmware: v2.12, hardware v0
- Groups: 1, Boilers: 2 (1 coffee, 1 steam)
- Steam boiler: pressurestat-controlled — **no temperature register, no software setpoint**
- Flow meter: FALSE (volumetric dosing not available on this machine)
- Main board MCU: ATmega32 @ 8 MHz, 9600 baud UART

---

## Verified Command Checksums

| Command String | Checksum calc | Result |
|---|---|---|
| `W00E10001` + `81` | sum(W,0,0,E,1,0,0,0,1,8,1) mod 256 | 0x57 ✓ |
| `W00E10001` + `01` | sum(W,0,0,E,1,0,0,0,1,0,1) mod 256 | 0x4F ✓ |
| `W00E10001` + `82` | sum(W,0,0,E,1,0,0,0,1,8,2) mod 256 | 0x58 ✓ |
| `W0007000203A2` | sum(W,0,0,0,7,0,0,0,2,0,3,A,2) mod 256| 0xB6 ✓ |
| `R40000023` | sum(R,4,0,0,0,0,0,2,3) mod 256 | 0xDB ✓ |

---

## Pending Verification (empirical tests once board is running)

1. **Pre-infusion timing unit**: Write 0x05 to 0x0101, observe wet-time duration
2. **Standby command**: Write 0x01/0x00 to 0x0406, observe machine response
3. **Brew stop**: Send `W80000001` + CS during active shot, observe pump stop
4. **Pre-infusion mode K2 registers**: 0x0136 and 0x0150 — likely irrelevant on single-group Mini

---

*Last updated: 2026-05-23*
*Sources: firmware binary analysis (lm_gateway_backup.bin), PulseView logic analyser captures, La Marzocco Home APK v2.1.3 + v3.1.6*

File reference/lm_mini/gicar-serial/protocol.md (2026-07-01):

# Ascaso Baby T Protocol Documentation

## Overview

The Ascaso Baby T uses a serial communication protocol where commands and responses are sent as ASCII strings. The protocol is used to read machine state and send configuration commands.

## Serial Communication Settings

- Baud rate: `115200`
- 8 data bits, no parity, 1 stop bit

## Protocol Format

### Read Request Format

```
r000500D7[CHECKSUM]
```

- `r` - Identifies this as a read request
- `000500D7` - read `00D7` (215) bytes, starting at offset `0005`
- `[CHECKSUM]` - Two-character hex checksum

### Read Response Format

```
r000500D7[PAYLOAD][CHECKSUM]
```

- `r000500D7` - Mirror the request, minus the checksum
- `[PAYLOAD]` - Hex-encoded machine state data (can be hundreds of bytes)
- `[CHECKSUM]` - Two-character hex checksum

### Write Command Format

```
w[OFFSET][LENGTH][DATA][CHECKSUM]
```

- `w` - Identifies this as a write command
- `[OFFSET]` - Four-character hex offset from memory position '5'
- `[LENGTH]` - Four-character hex length of data to write
- `[DATA]` - Hex-encoded data to write
- `[CHECKSUM]` - Two-character hex checksum

example for `steam on`: `w005600010164`

### Write Response Format

```
w[OFFSET][LENGTH][OK][CHECKSUM]
```
example for `steam on`: `w00560001OK9D`

## Checksum Calculation

Checksums are calculated as follows:  
1. Sum the ASCII values of each character in the string (excluding the checksum characters)  
2. Take the result modulo 256  
3. Format as a two-character hex value  
eg. `sum(ord(c) for c in response[:-2]) % 256`

## Memory Map

The machine's memory is organized with specific offsets for different settings:

- **0-35**: General settings
- **36-50**: Language and configuration settings
- **53-82**: Temperature settings
- **83-110**: Steam and dose settings
- **124-132**: Power state and timer settings
- **134-152**: Counters (read-only)
- **210-212**: Total counter

## Data Types

The protocol supports several data types:
- `u8`: 8-bit unsigned integer (1 byte)
- `u16le`: 16-bit unsigned integer, little-endian (2 bytes)
- `u32le`: 32-bit unsigned integer, little-endian (4 bytes)

## Value Transformations

Some values have specific transformations:  
1. **Multipliers**: Values like temperature are stored multiplied by 10 (e.g., 93.5°C is stored as 935)  
2. **Predefined states**: Values like power state use specific integers (e.g., 6 for "on", 4 for "off")  
3. **Expressions**: Some values are interpreted through expressions (e.g., "value > 0" for "on")

## Communication Flow

1. **Reading current state**:
   - Send a read request (`r000500D7[CHECKSUM]`)
   - Receive a response with the full machine state
   - Parse the response to extract specific values

2. **Writing a setting**:
   - Prepare the payload with the modified value
   - Build a write command with the appropriate offset and length
   - Send the command to the machine
   - Wait for acknowledgment

## Examples

### Example Read Request
```
r000500D7E7
```
### Example Read Response
```
r000500D7FFFFFFFFFFFFFFFFFFFFFFFFFFFFFFFFFFFFFFFFFFFFFFFFFFFFFF0101020200010100011E1E1E1E002600282D000000A2031E000F0028000A00E30450000F006400050078000002D101000102F2032D00010101000068006A008E00680170176E00DC0096002C0170176E00DC0096002C017017080C100101016464646400060004000000000000000000000000000000050000000000000000000000000000000000000000000000000000000000000000000000000000000000000000000000000000000000000009000000A41E0000A41E00000000E1
```

### Example Write Command (turn steam boiler on)
```
w005600010164
```
- Offset: `0056` (corresponds to steam_state offset: 0x56 = 86)
- Length: `0001` (1 byte)
- Data: `01` (value for "on")
- Checksum: `64`

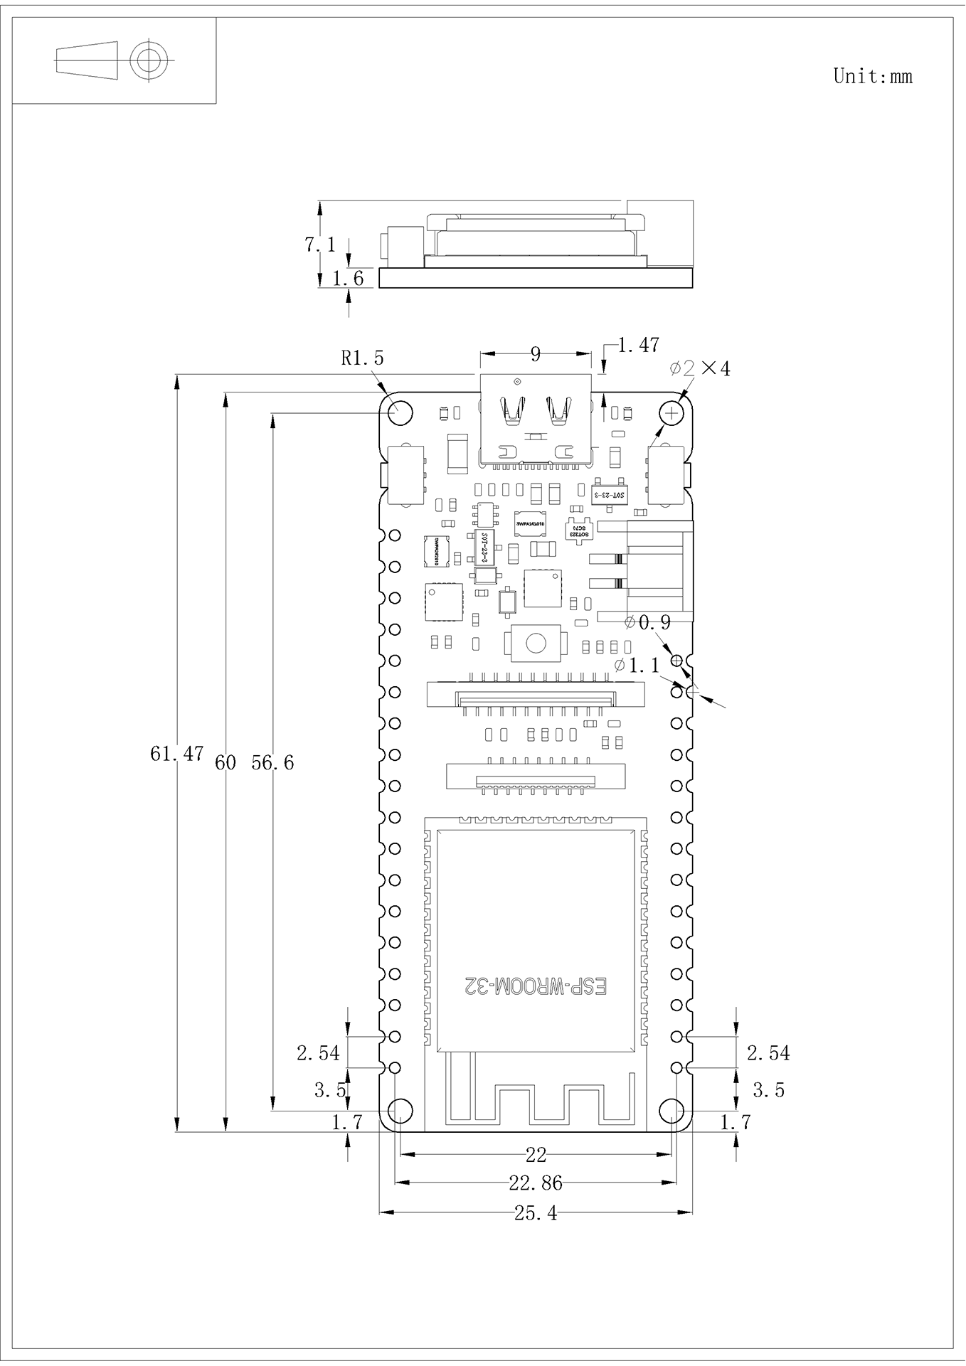
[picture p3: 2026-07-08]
reference/dfrobot/cad/DFR0975_2D_CAD.png

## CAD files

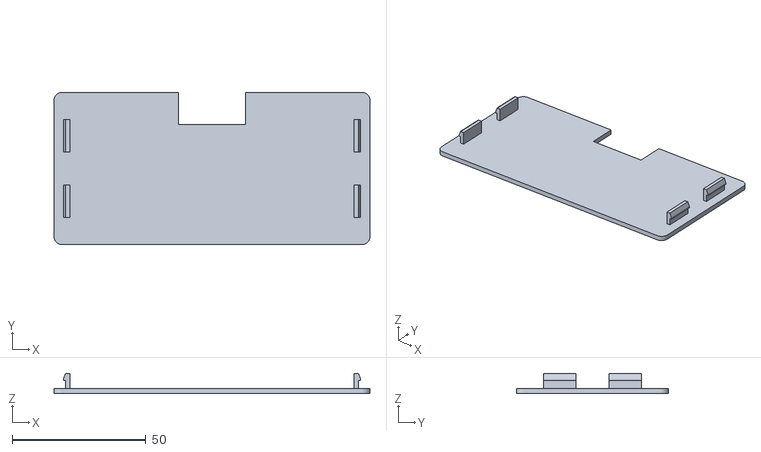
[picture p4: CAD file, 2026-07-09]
cad/cover_group_bottom.stl
118.2 x 57.0 x 7.60

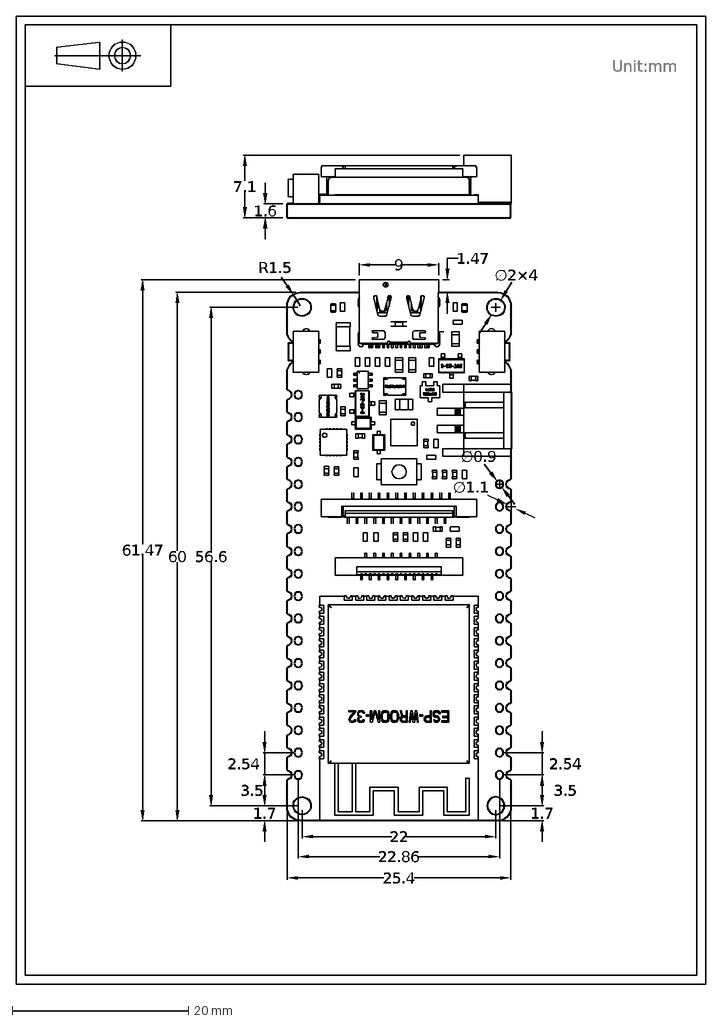
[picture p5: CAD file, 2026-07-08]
reference/dfrobot/cad/DFR0975_2D_CAD.dxf
Unit:mm
22
25.4
22.86
56.6
60
61.47
9
1.47
∅2×4
R1.5
∅0.9
∅1.1
1.7
3.5
2.54
1.6
7.1

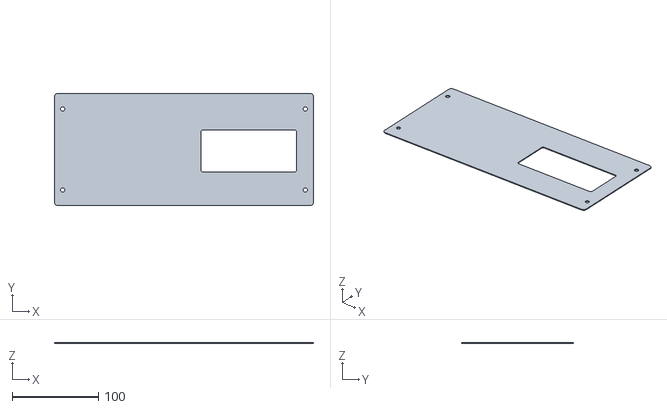
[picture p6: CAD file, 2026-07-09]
cad/cover_group_fit_test.stl
300.0 x 130.0 x 1.00

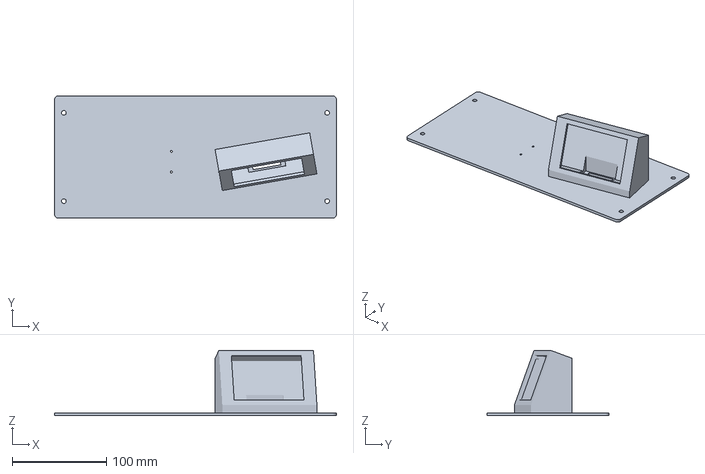
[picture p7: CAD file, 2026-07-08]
cad/cover_group.3mf
300.0 x 130.0 x 69.4 mm

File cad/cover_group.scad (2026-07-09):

// ─────────────────────────────────────────────────────────────────────────────
// La Marzocco Linea Mini — replacement COVER GROUP LMR (part C.1.743)
// with integrated DFRobot DFR1092 3.5" touchscreen pod for the ESP32-S3
// controller (LineaMini_C6 project, S3 cutover).
//
// HOW TO USE (OpenSCAD basics):
//   * Open this file in OpenSCAD, press F5 to preview, F6 + File>Export>STL
//     to slice. Edit any variable in the PARAMETERS block, F5, repeat.
//
// Stock-part dimensions measured with calipers off the real C.1.743
// (2026-07-08): 300 x 130 x 3 mm flat plate, no flanges, 4 mm corner radius,
// four 5 mm round mounting holes 18 mm in from front/back edges; left/right
// inset revised to 9.5 mm (2026-07-09: +0.5 mm gap each side vs the 9 mm
// second fit test).
//
// Display pod (v2, 2026-07-09): right-hand side, screen at 20 deg from
// horizontal, facing the front directly (no yaw), 10 mm wider than the
// module on EACH side for cable slack. The pod is SEALED — no external
// hatch. Its only opening is downward: an installation aperture in the
// panel underneath, through which the DFR1092 (screws onto M2 bosses
// behind the face skin) and the FireBeetle (screws onto M2 bosses on the
// inside of the pod's rear wall — "the back panel") are fitted. A snap-in
// cover closes the aperture from below, with an open cable notch on its
// rear edge for the harness coming up from inside the machine.
//
// Datum: X=0,Y=0 = FRONT-LEFT corner of the panel top face. X right (300),
// Y back (130), Z up. "Front" = barista-facing edge.
// ─────────────────────────────────────────────────────────────────────────────

// ── PARAMETERS — panel (measured stock C.1.743) ──────────────────────────────
panel_len      = 300;
panel_wid      = 130;
panel_thick    = 3;
corner_r       = 4;
mount_hole_d   = 5.0;
// 9.5mm in from left/right edges, 18mm in from front/back
mount_holes    = [ [9.5,18], [290.5,18], [9.5,112], [290.5,112] ];

// ── PARAMETERS — display pod ─────────────────────────────────────────────────
disp_angle     = 20;     // screen tilt from horizontal (deg)
pod_center_x   = 225;    // pod centre X (right side, clear of the 290.5 holes)
pod_center_y   = 60;     // pod centre Y
pod_fillet     = 2;      // fillet on the housing outline corners

// DFR1092 module (reference/dfrobot/dfr1092-3.5-display.md + vendor STEP)
disp_mod_w     = 95.0;   // module outline, landscape
disp_mod_h     = 54.5;
disp_mod_t     = 5.7;
disp_hole_dx   = 90;     // M2 mounting hole spacing
disp_hole_dy   = 50;
disp_hole_d    = 1.8;    // self-tap M2 into printed boss
disp_view_w    = 73.94;  // active area
disp_view_h    = 48.96;
disp_margin    = 1.0;    // aperture margin around active area

pod_wall       = 3;      // frame walls + face skin thickness
pod_clear      = 0.6;    // module fit clearance
side_extra     = 10;     // extra housing width EACH side for cable slack
disp_boss_h    = 4;      // module standoff behind the face skin
wire_space     = 15;     // interior depth behind the module: harness room
                         // PLUS the FireBeetle stack on the rear wall
                         // (boss 3 + board 1.6 + components ~4)
cheek_t        = 3;      // side cheek / rear wall thickness under the slab

// Panel aperture under the pod (installation + cabling) and its snap cover
apt_clear      = 3;      // aperture inset from the pod's under-void footprint
cover_t        = 2;      // bottom cover plate thickness
cover_lip      = 4;      // cover overlap beyond the aperture, all round
cover_clear    = 0.3;    // tab fit clearance against the aperture edges
tab_w          = 12;     // snap tab width
tab_t          = 1.6;    // snap tab thickness (flexes to clear the nub)
nub_proud      = 0.8;    // nub protrusion past the aperture edge
notch_w        = 25;     // open cable notch, middle of the cover's REAR edge
notch_d        = 12;     // notch depth into the cover

// ── ESP32-S3 (FireBeetle DFR0975) mounting ───────────────────────────────────
// No printed bosses: the rear-wall bosses clashed with the display's mounting
// screws (removed 2026-07-09). Board fixing inside the pod is TBD by the user
// (adhesive standoffs / velcro / a small carrier). For reference the board is
// 25.4 x 61.47 with 2.0mm holes on a 22 x ~51.4 grid.

// What to render (edit + F5/F6):
//   "all"          assembly preview: panel + pod + bottom cover in place
//   "main"         panel + pod only -> export cover_group.stl
//   "bottom_cover" cover alone, flat on the bed -> cover_group_bottom.stl
//   "fit_test"     first fit_test_h mm of the main part only -- quick print
//                  to verify outline/holes/pod footprint on the machine
render_part    = "all";
fit_test_h     = 1;      // fit-test slice height (mm)

$fn = 48;

// ── Derived ──────────────────────────────────────────────────────────────────
housing_t  = pod_wall + disp_boss_h + disp_mod_t + wire_space;  // face depth
slab_w     = disp_mod_w + 2*(pod_wall + pod_clear + side_extra); // outer width
slab_l     = disp_mod_h + 2*(pod_wall + pod_clear);              // face length
footY0     = -housing_t * sin(disp_angle);   // front-most footprint extent
footY1     =  slab_l    * cos(disp_angle);   // footprint depth at panel level
back_h     =  slab_l    * sin(disp_angle);   // slab underside height at rear
foot_mid   = (footY0 + footY1) / 2;

// Panel aperture rectangle. Pod-local X/Y (pod frame origin = resting edge,
// x centred): inset apt_clear from the under-void's interior footprint
// (between the cheeks and the front/rear closures).
apt_w      = slab_w - 2*cheek_t - 2*apt_clear;
apt_y0l    = apt_clear;                       // pod-local front edge
apt_l      = (footY1 - cheek_t) - 2*apt_clear;
// world-frame position of the aperture's front-left corner
apt_x0     = pod_center_x - apt_w/2;
apt_y0     = pod_center_y - foot_mid + apt_y0l;

// ── Primitives ───────────────────────────────────────────────────────────────
module rounded_plate(l, w, t, r) {
    linear_extrude(t)
        offset(r) offset(-r)
            square([l, w]);
}

module rounded_rect(w, l, r) {
    offset(r) offset(-r)
        translate([-w/2, 0])
            square([w, l]);
}

// Pod frame: origin = the slab's resting edge on the panel top, centred in
// X. No yaw — the face looks straight forward.
module pod_transform() {
    translate([pod_center_x, pod_center_y, panel_thick])
        translate([0, -foot_mid, 0])
            children();
}

// Slab local frame (before tilt): the screen FACE is the plane z=housing_t;
// z=0 is the slab's underside plane (open — the pod's only opening, facing
// the under-void and the panel aperture). x centred, y from 0 (front/low
// edge) to slab_l. tilt() leans it back by disp_angle about X through y=0,z=0.
module tilt() {
    rotate([disp_angle, 0, 0])
        children();
}

// ── Panel ────────────────────────────────────────────────────────────────────
module panel() {
    difference() {
        rounded_plate(panel_len, panel_wid, panel_thick, corner_r);
        for (h = mount_holes)
            translate([h[0], h[1], -1])
                cylinder(d = mount_hole_d, h = panel_thick + 2);
        // installation aperture under the pod (display + FireBeetle go in
        // from below; the snap cover closes it from underneath)
        translate([apt_x0, apt_y0, -1])
            linear_extrude(panel_thick + 2)
                offset(2) offset(-2)
                    square([apt_w, apt_l]);
    }
}
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

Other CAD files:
cad/cover_group.stl

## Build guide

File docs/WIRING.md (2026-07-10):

# Wiring

How to connect the FireBeetle 2 ESP32-S3 (DFR0975) to the DFR1092 display
and to the Linea Mini's CN11 connector. Pin assignments below are the single
source of truth in `platformio.ini` (`[env:lm_controller_s3]` build flags) —
if this document and the build flags ever disagree, the build flags win.

## 1. Display + touch (DFR1092)

The DFR1092 plugs straight into the DFR0975's **18-pin GDI FPC connector**
with the ribbon cable supplied with the display — no discrete wiring is
needed. Power, SPI (display), I²C (touch), backlight, and reset all run over
the one cable.

For reference (or if you are hand-wiring instead of using the GDI cable),
the GDI connector maps to these ESP32-S3 GPIOs:

| Signal | GPIO | Notes |
| --- | --- | --- |
| SPI SCLK | 17 | Display clock |
| SPI MOSI | 15 | Display data out |
| SPI MISO | 16 | Display data in |
| Display CS | 18 | Chip select |
| Display DC | 3 | Data/command |
| Display RST | 38 | Reset |
| Backlight | 21 | PWM-capable |
| Touch SCL | 2 | GT911 I²C clock |
| Touch SDA | 1 | GT911 I²C data |
| Touch INT | 13 | GT911 interrupt |
| Touch RST | 12 | GT911 reset |

**Do not reuse GDI pins for anything else.** GPIO 1/2/3/13 in particular
look temptingly free on the header but are carrying touch and display
signals — an earlier bring-up put the GICAR UART on GPIO13 and got checksum
errors plus a dead touchscreen from bus contention.

## 2. Machine interface (CN11)

CN11 is a 4-pin connector on the machine's GICAR main board (E.1.059). It
carries power and a serial link:

| Pin | Signal | Direction | Level |
| --- | --- | --- | --- |
| 1 | GND | — | 0 V |
| 2 | RXD | machine ← controller | 2.5 V LVCMOS |
| 3 | TXD | machine → controller | 2.5 V LVCMOS |
| 4 | +12 V | machine → controller | 12 V |

> CN11 is labelled "RS-232" on some documentation, but the signals are
> empirically 2.5 V LVCMOS, **idle-low** — no RS-232 level shifter is needed
> (and fitting one would damage the board). Because the lines idle low, the
> firmware opens the UART with `invert=true`; this is already handled in
> `gicar.cpp`.

### Interface circuit

The adapter board, mounted beside the GICAR controller (green board) with the
CN11 cable, buck converter, and the series/pull-up resistors:

<p align="center">
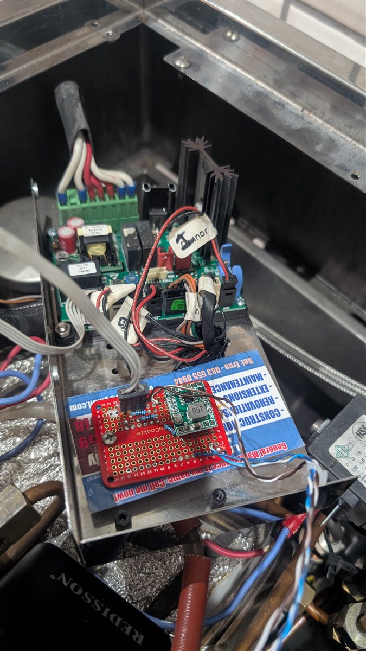
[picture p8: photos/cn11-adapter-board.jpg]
Perfboard adapter next to the GICAR board inside the machine: CN11 connection, buck converter module, and the series and pull-up resistors
  
</p>

```
CN11                        Adapter board                    FireBeetle 2 ESP32-S3
────                        ─────────────                    ─────────────────────
Pin 4 (+12V) ─────────────► [buck converter, set to 3.3V] ─► 3V3 pin
Pin 1 (GND)  ─────────────────────────────────────────────── GND pin

                              R1 300Ω          R3 10kΩ
Machine TXD  ─────────────────┤├────────┬──────┤├───────── 3V3
                                        │
                                        └────────────────► GPIO14 (GICAR RX)

                              R2 300Ω
Machine RXD  ◄────────────────┤├────────────────────────── GPIO44 (GICAR TX)
```

Bill of materials:

| Ref | Value | Purpose |
| --- | --- | --- |
| U1 | Buck converter module (≥0.8 A) | 12 V → 3.3 V board power, fed to the FireBeetle's 3V3 pin. Trim to 3.3 V **before** connecting the ESP32. |
| R1 | 300 Ω ¼ W | Series protection, machine TXD → GPIO14 |
| R2 | 300 Ω ¼ W | Series protection, GPIO44 → machine RXD |
| R3 | 10 kΩ ¼ W | Pull-up, GPIO14 → 3.3 V (lifts the machine's 2.5 V idle level above the S3's ~2.47 V V<sub>IH</sub> threshold) |

The series resistors limit fault current to ~10 mA and add negligible
distortion at 9600 baud. The pull-up is only needed on the receive line;
GPIO44 already drives a full 3.3 V swing, which the machine accepts.

### ⚠️ The TXD/RXD labels at the plug are crossed

On the harness used to develop this project, the TXD/RXD labels at the CN11
plug were **swapped** relative to the actual signals (confirmed by loopback
test at the plug). This class of mistake has bitten this project twice, so:

1. Before wiring, run a **loopback test**: disconnect from the machine,
   bridge the two signal wires at the machine end of your harness, and
   verify the ESP32 receives back exactly what it sends.
2. After connecting to the machine, trust **decoded frames, not labels**. If
   the wiring is right, the serial log shows clean GICAR R-frames within a
   couple of seconds of the machine powering on. If you see nothing or
   garbage, swap the two signal wires (or swap `GICAR_RX_PIN`/`GICAR_TX_PIN`
   in `platformio.ini`) and try again — no harm is done either way thanks to
   the series resistors.

### Pin choice notes (ESP32-S3 / DFR0975)

- **GPIO14 (RX) / GPIO44 (TX)** are the verified-working pair.
- **Avoid GPIO43** on the DFR0975 — it only reached 0.75 V under drive
  during bring-up (cause unknown).
- **Avoid all GDI pins** (see section 1).
- The UART runs at **9600 8N1, inverted**, with an enlarged 2 KB RX buffer —
  all configured in firmware; nothing to set up in hardware.

## 3. Power

The controller is powered from CN11 pin 4 (+12 V) through the buck
converter, set to **3.3 V** and fed straight into the FireBeetle's 3V3 pin
(bypassing the board's own regulator). Budget ≥500 mA (ESP32-S3 with WiFi
active plus the display backlight). Set-up procedure for the buck module:

1. Power it from a bench supply at 12 V with no load.
2. Trim the output to 3.3 V.
3. Connect the ESP32, boot it with WiFi up, and re-measure — re-trim if the
   output sags below ~3.1 V (the ESP32-S3's minimum is 3.0 V).

> Because the 3V3 pin is fed directly, avoid plugging in USB while the
> machine is powering the board — the buck output and the FireBeetle's
> onboard USB regulator would be driving the same rail. Power from one
> source at a time.

Route the cable away from the mains wiring and heating elements inside the
machine.

## 4. Verification checklist

- [ ] Buck output 3.3 V unloaded, ≥3.1 V with the controller booted and WiFi up
- [ ] Loopback test at the CN11 plug passes byte-perfect
- [ ] Controller boots, display renders, touch responds
- [ ] GICAR frames decode within seconds of machine power-on (live boiler
      temperature on the main screen confirms RX)
- [ ] A write command (e.g. changing target temperature from the settings
      menu) takes effect on the machine (confirms TX)
- [ ] No component warm to the touch after 30 minutes of operation

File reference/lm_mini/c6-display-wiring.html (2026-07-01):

# 2.4" ILI9341 SPI Display

# → Firebeetle 2 ESP32-C6 Wiring Guide

Temporary display while DFR1092 GDI display is in transit · Pins match GDI connector so no rewiring needed on arrival

## Hardware Overview

Display — W18366 (Waveshare 2.4")

Driver IC | ILI9341
Resolution | 240 × 320 (portrait native)
Interface | 4-wire SPI
Logic voltage | 3.3 V
Touch | None
Backlight | BL pin (PWM or tie to 3V3)

Controller — Firebeetle 2 ESP32-C6 (DFR1075)

CPU | RISC-V single-core 160 MHz
WiFi | 802.11ax (WiFi 6)
BLE | BLE 5
Logic voltage | 3.3 V GPIO
SPI bus | SCLK=GPIO23, MOSI=GPIO22, MISO=GPIO21
GDI connector | 18-pin FPC (used for display control signals)

## Wiring — Display to Firebeetle C6

✓ These GPIO assignments match the Firebeetle C6 GDI connector exactly. When the DFR1092 display arrives, swap the display module — no rewiring needed on the Firebeetle side.

Display Pin | | Firebeetle C6 Pin | GPIO | Type | Notes
VCC | → | 3V3 | — | POWER | 3.3 V supply only — do not use 5 V
GND | → | GND | — | POWER | Any GND pin
DIN | → | MOSI | GPIO22 | SPI | SPI data out (host → display)
CLK | → | SCK | GPIO23 | SPI | SPI clock
CS | → | D6 | GPIO1 | CTRL | Display chip select (active LOW)
DC | → | D2 | GPIO8 | CTRL | Data / Command select
RST | → | D3 | GPIO14 | CTRL | Hardware reset (active LOW)
BL | → | D13 | GPIO15 | CTRL | Backlight enable. Also onboard LED — backlight will mirror LED state

⚠ No MISO connection needed. The ILI9341 is write-only in this configuration. Leave the Firebeetle MISO (GPIO21) unconnected. Also no touch on this module — leave TOUCH_CS (GPIO6) unconnected.

## Firebeetle C6 Physical Header Reference

Header label | GPIO | Connect to display pin
3V3 | — | VCC
GND | — | GND
SCK / IO23 | GPIO23 | CLK
MOSI / IO22 | GPIO22 | DIN
D6 / IO1 | GPIO1 | CS
D2 / IO8 | GPIO8 | DC
D3 / IO14 | GPIO14 | RST
D13 / IO15 | GPIO15 | BL

## Gicar Serial Port Wiring (CN11 → Firebeetle C6)

ℹ The Gicar UART was on GPIO16/17 on the original ESP32 board. Those pins are not broken out on the Firebeetle C6 header, so the UART is remapped to GPIO5 (TX) and GPIO4 (RX). The button moves from GPIO14 (now LCD_RST) to GPIO10.

CN11 Signal | | Firebeetle C6 Pin | GPIO | Notes
+12 V | → | Buck converter in | — | 12 V → 5 V buck → Firebeetle 5V pin (same as original board)
GND | → | GND | — | Common ground
TXD (machine sends) | → | D4 | GPIO4 | GICAR_RX_PIN — machine TXD → ESP32 RX. Add 10 kΩ pull-up to 3.3 V (2.5 V signal is marginal for VIH)
RXD (machine receives) | → | D5 | GPIO5 | GICAR_TX_PIN — ESP32 TX → machine RXD

⚠ 10 kΩ pull-up required on RX (GPIO4). CN11 TXD idles at 2.5 V LVCMOS — below ESP32-C6's guaranteed VIH. A 10 kΩ resistor from GPIO4 to 3.3 V ensures reliable logic-high detection. The TX line (GPIO5) needs no pull-up.

Button — moved to GPIO10

Signal | | Firebeetle C6 Pin | GPIO | Notes
Button 1 (active LOW) | → | D10 | GPIO10 | Moved from GPIO14 (now LCD_RST). Wire between GPIO10 and GND — INPUT_PULLUP in firmware
Button 2 (active LOW) | → | D0 | GPIO2 | Wire between GPIO2 and GND — INPUT_PULLUP in firmware

## gicar.h and button.cpp — Pin Updates

// src/gicar.h — updated for Firebeetle C6
#define GICAR_RX_PIN    4   // D4 — CN11 TXD (machine → ESP). Was GPIO17.
#define GICAR_TX_PIN    5   // D5 — CN11 RXD (ESP → machine). Was GPIO16.

// src/button.cpp — updated for Firebeetle C6
#define BTN_PIN         10  // D10 — moved from GPIO14 (now LCD_RST)
#define BTN2_PIN        2   // D0  — second button

## platformio.ini — Changes Required for This Display

ℹ These settings are for the temporary 2.4" ILI9341. When the DFR1092 3.5" display arrives, change back to ILI9488_DRIVER, TFT_WIDTH=320, TFT_HEIGHT=480.

; platformio.ini — temporary ILI9341 build for Firebeetle C6 bring-up

[env:lm_controller]
platform  = espressif32
board     = esp32-c6-devkitc-1    ; Firebeetle C6 — closest matching board
framework = arduino

monitor_speed = 115200

board_build.partitions = huge_app.csv
board_build.filesystem = littlefs

build_flags =
    -DCORE_DEBUG_LEVEL=0
    -I include
    -DLV_CONF_INCLUDE_SIMPLE
    ; ── TFT_eSPI: ILI9341 2.4" SPI display (240×320 portrait native) ──
    -DUSER_SETUP_LOADED=1
    -DILI9341_DRIVER=1
    -DTFT_WIDTH=240
    -DTFT_HEIGHT=320
    -DTFT_MOSI=22     ; MOSI — Firebeetle C6 GDI / DIN on display
    -DTFT_SCLK=23     ; SCK  — Firebeetle C6 GDI / CLK on display
    -DTFT_CS=1        ; D6   — Firebeetle C6 GDI / CS on display
    -DTFT_DC=8        ; D2   — Firebeetle C6 GDI / DC on display
    -DTFT_RST=14      ; D3   — Firebeetle C6 GDI / RST on display
    -DTFT_BL=15       ; D13  — Firebeetle C6 GDI / BL on display
    -DTFT_BACKLIGHT_ON=HIGH
    ; No TOUCH_CS — this display has no touch
    -DLOAD_GLCD=1
    -DLOAD_FONT2=1
    -DLOAD_FONT4=1
    -DLOAD_FONT6=1
    -DLOAD_FONT7=1
    -DLOAD_FONT8=1
    -DLOAD_GFXFF=1
    -DSMOOTH_FONT=1

## Firmware Changes Required (C6 port)

File | Change | Reason
platformio.ini | See above — board, driver IC, SPI pins | New board + new display
src/scale.cpp | xTaskCreatePinnedToCore(..., 0) → xTaskCreate(...) | C6 is single-core — no core 0/1
src/main.cpp | OTA task: xTaskCreatePinnedToCore(..., 1) → xTaskCreate(...) | Same — single-core C6
src/main.cpp | Update SCREEN_W to 240, SCREEN_H to 320 for temp display | ILI9341 is 240×320 not 480×320
src/gicar.h | Update GICAR_TX_PIN / GICAR_RX_PIN to available C6 GPIOs | GPIO16/17 may not be exposed on C6 board
src/button.cpp | Move BTN_PIN from 14 to a free GPIO (e.g. GPIO4) | GPIO14 is now LCD_RST

⚠ SCREEN_W / SCREEN_H and LVGL buffer: The UI was built at 480×320. At 240×320 the layout will be compressed horizontally. This is expected for the temporary bring-up — full layout will restore when the DFR1092 (320×480) arrives.

## When DFR1092 3.5" GDI Display Arrives

✓ Wiring on the Firebeetle side is identical — no rewiring needed. Plug the 18-pin FPC into the GDI connector on the Firebeetle C6.

platformio.ini changes for DFR1092:

- Change ILI9341_DRIVER → ILI9488_DRIVER
- Change TFT_WIDTH=240 → TFT_WIDTH=320
- Change TFT_HEIGHT=320 → TFT_HEIGHT=480
- Add -DTOUCH_CS=6 (GT911 uses I2C not SPI — see touch.cpp note below)
- Restore SCREEN_W=480, SCREEN_H=320 in main.cpp

touch.cpp changes for DFR1092:

- Replace XPT2046 (SPI resistive) with GT911 (I2C capacitive) driver
- GT911 address: 0x5D or 0x14 — confirm with I2C scan
- I2C pins: SDA=GPIO19, SCL=GPIO20 (already on Firebeetle header)

LM Mini Controller — C6 bring-up wiring guide · Generated 2026-06-26

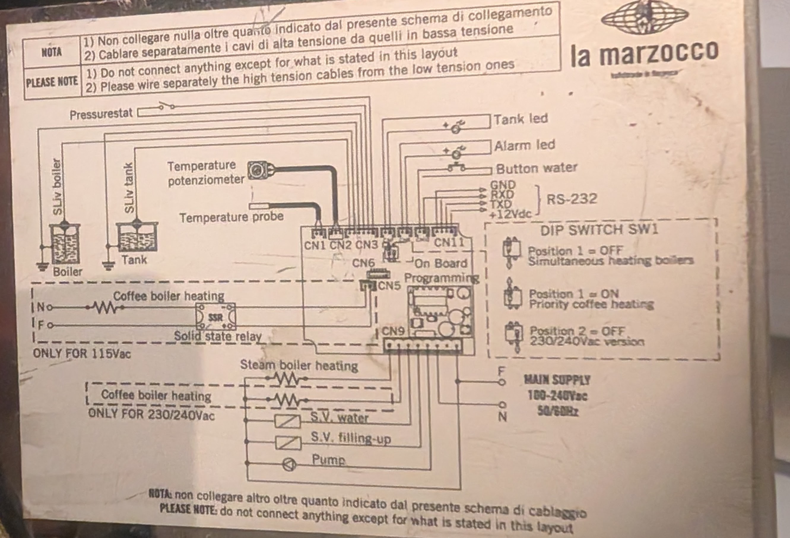
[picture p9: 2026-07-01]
reference/lm_mini/photos/PXL_20260315_222120411_full-wiring-schematic.jpg

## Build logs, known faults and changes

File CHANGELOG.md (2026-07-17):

# Changelog

Human-facing version history for the Linea Mini controller firmware. The
version string lives in `include/version.h` (`FW_VERSION`) and is bumped on
every deployed update; not every version gets a GitHub release — releases are
cut when a batch of field-tested changes is stable.

## v0.37 — 2026-07-17

Combined release covering the v0.31–v0.37 field updates.

### Added
- **Standby confirmation** — STANDBY pill at the top of the main screen with a
  hold-to-arm and yes/no confirm dialog, so standby can't be triggered by an
  accidental tap.
- **Scale Bluetooth on/off** — new "Scale BT" setting in the menu
  (NVS-persisted). Turning it off disconnects the scale and stops all BLE
  scanning.
- **SCALE status pill** — top-right of the main screen, showing scale
  connection state. Tapping it while disconnected triggers an immediate
  fast scan (and re-enables Scale BT if it was off), instead of waiting for
  the next idle scan cycle.
- **HEAT / STEAM status dots** — the old display-only HEAT and STEAM buttons
  are now two small round indicators at the top-left of the main screen.

### Changed
- **Main screen layout rework** — temperature reading moved to the centre of
  the screen, scale weight enlarged and placed between temperature and the
  clean counter, clean counter moved directly above the MENU button.
- **BLE idle scan interval 15 s → 60 s** — each scan actively runs for 10 s,
  so a 15 s pause meant ~40 % radio duty on the ESP32's shared 2.4 GHz
  radio, degrading WiFi/MQTT and making OTA transfers fail on marginal
  links. Fast-scan behaviour after a disconnect is unchanged.

### Fixed
- Brew-by-weight stop no longer has standby side effects; standby button
  responsiveness improved (v0.31).
- OTA tooling: `tools/ota_pull.py` now paces sends against the device's real
  consumption (small SO_SNDBUF + chunked writes) so a stalled transfer is
  reported instead of a false "served" success, and waits up to 10 minutes
  for the fetch; `tools/ota_upload.py` defaults its espota callback to port
  8070 to reuse the existing firewall rule.

## v0.30 — 2026-07-09
- GitHub-release OTA verified end-to-end: on-device check → confirm →
  install → reboot from a published release.

## v0.29
- GitHub update check frees the radio: BLE suspend/resume around the TLS
  fetch so the check completes reliably.

## v0.28 — 2026-07-09
- GitHub OTA dress-rehearsal release.

## v0.27
- Fixed GitHub install hang: manual streamed download replacing
  `httpUpdate.update()`, plus on-screen confirm/progress UI.

## v0.26
- Fixed GitHub OTA check (TLS buffers out of internal RAM) and CI-build
  credential seeding (CI binaries compile with blank secrets and never
  overwrite a device's stored WiFi/MQTT configuration).

## v0.25
- GitHub-release OTA: on-device update check and tagged-release CI pipeline
  (`.github/workflows/release.yml`).

## v0.24
- Reliable LAN OTA: MQTT-triggered HTTP-pull path plus hardened espota
  fallback.

## v0.23
- 20-second shot/flush rule (shorter pump runs count as flushes, not shots),
  cleaning-countdown reminder, and a clean-interval setting.

## v0.22
- Settings menu legibility and navigation buttons.

## v0.21
- Standby scheduling (daily wake/sleep, timezone-aware) and tap-to-wake
  overlay.

## v0.20
- HEAT indicator, MENU long-press affordance, slimmer settings menu.

## v0.18
- Machine-setpoint readback and machine-aware status dot.

## v0.17
- First working OTA updates; status line replaced by a connectivity dot.

## v0.16
- UI rework: edge adjusters, CLEAN on the main screen, bold type,
  brew-by-weight auto-offset. Guided backflush cleaning cycle with verified
  GICAR choreography.

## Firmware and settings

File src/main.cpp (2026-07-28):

// LineaMini_C6 -- Phase 6: WiFi/OTA/MQTT/BLE scale/shot log.
//
// Boots the serial console, initializes the display + LVGL, touch, and the
// ported espresso UI, brings up WiFi (DHCP) + OTA + BLE scale + MQTT, then
// the GICAR machine-interface UART driver last (see the ordering note in
// setup()). Prints the build fingerprint as a repeating heartbeat.

#include <Arduino.h>
#include <WiFi.h>
#include <ArduinoOTA.h>
#include <Update.h>   // Update.abort() — clear a wedged Update state on OTA error
#include <lvgl.h>

// Auto-generated by tools/gen_build_info.py on every build. It does not exist
// until the first `pio run`; that is expected. Provides FW_GIT_HASH /
// FW_BUILD_TIME.
#include "build_info.h"

// Machine-interface layer: wraps gicar.cpp's raw protocol driver in the
// MachineState struct (connected/coffee_temp_c/brew_active/...) that ui.cpp
// actually reads.
#include "machine.h"

// Display + LVGL bring-up (ILI9488 panel via LovyanGFX, LVGL driver registration).
#include "display.h"

// Ported LVGL espresso UI (pure widget logic; reads machine/scale/settings state).
#include "ui.h"

// GT911 capacitive touch -> LVGL pointer indev (drives the UI's click callbacks).
#include "touch.h"

// NVS-persisted user settings (coffee temp, brew weight target, shot count, ...).
#include "settings.h"

// BLE coffee scale (Felicita Arc / Bookoo Themis) -- weight/flow for brew-by-weight.
#include "scale.h"

// Home Assistant MQTT discovery + state/command topics.
#include "mqtt.h"

// MQTT-triggered HTTP-pull OTA (queued in the MQTT callback, run from loop()).
#include "ota_http.h"

// NVS-backed WiFi credential storage (falls back to secrets.h WIFI_SSID/PASSWORD).
#include "wifi_config.h"

// SoftAP + captive portal for first-time WiFi setup (no saved NVS credentials).
#include "wifi_ap.h"

// Compile-time WiFi/MQTT/OTA fallback credentials (gitignored; see secrets.h.example).
#include "secrets.h"

// Serial + TCP (port 4444) diagnostic log sink, used throughout gicar.cpp etc.
#include "wlog.h"

// LittleFS-backed shot history (start/end detection, temp/weight samples, JSON API).
#include "shot_log.h"

// RAM-only per-shot flow/weight curve, published to Home Assistant at brew end.
#include "flow_log.h"

// ── WiFi + OTA ────────────────────────────────────────────────────────────────
//
// OTA runs in its own FreeRTOS task (this chip is single-core, so it still
// shares CPU time with loop() via the scheduler). Matches the reference
// bring-up's ota_task() exactly -- see the OTA-on-core-1/WiFiUDP note below.

// mDNS/OTA hostname. Per-env: the S3 env overrides via build_flags so both
// boards can be on the network at once during the port (same name = mDNS fight
// and OTA/wlog target the wrong board).
#ifndef DEVICE_HOSTNAME
#define DEVICE_HOSTNAME "linea-mini-c6"
#endif

static void ota_task(void*) {
    ArduinoOTA.setHostname(DEVICE_HOSTNAME);
    if (strlen(OTA_PASSWORD) > 0) ArduinoOTA.setPassword(OTA_PASSWORD);

    ArduinoOTA.onStart([]() {
        Serial.println("OTA start");
        // Fully release the radio: pausing the BLE scan is not enough on the
        // S3's single shared 2.4GHz radio — NimBLE must be deinitialized to free
        // it (proven 2026-07-08: transfers died mid-stream while BLE was live).
        scale_radio_release();
        // Legal only after NimBLEDevice::deinit() — throws while BLE is init'd.
        WiFi.setSleep(false);
        ui_ota_start();
    });
    ArduinoOTA.onEnd([]()   { Serial.println("\nOTA done"); });
    ArduinoOTA.onProgress([](unsigned int prog, unsigned int total) {
        // Feed the same on-screen percent readout the manual OTA path drives
        // (main-screen diagnostic line, via ota_http_progress()). Plain volatile
        // write — no LVGL here, safe from this OTA task.
        if (total) ota_http_set_progress((uint8_t)((uint64_t)prog * 100 / total));
    });
    ArduinoOTA.onError([](ota_error_t e) {
        Serial.printf("OTA error[%u]\n", e);
        // A failed transfer wedges the Update state machine (arduino-esp32
        // #8393) so every later attempt instant-aborts. Abort to clear it, then
        // reboot for a clean radio/BLE state on the next attempt.
        Update.abort();
        ESP.restart();
    });

    bool armed = false;
    for (;;) {
        if (WiFi.status() == WL_CONNECTED) {
            if (!armed) {
                ArduinoOTA.begin();
                armed = true;
                wlogf("[ota] ready\n");
            }
            ArduinoOTA.handle();
        } else {
            // WiFi dropped — disarm so we re-call begin() on next reconnect.
            // ArduinoOTA uses a UDP socket that must be re-bound after reconnect.
            if (armed) {
                ArduinoOTA.end();
                armed = false;
                wlogf("[ota] disarmed (WiFi down)\n");
            }
        }
        vTaskDelay(1);
    }
}

// Stored at init so wifi_tick() can retry without re-reading NVS every call.
static const char* s_wifi_ssid    = nullptr;
static const char* s_wifi_pass    = nullptr;
static uint32_t    s_wifi_retries = 0;   // number of explicit reconnect attempts

// NTP is (re)synced from wifi_tick()'s connected branch, not once at boot: a
// boot-only sync leaves the clock free-running on the ESP32's RC oscillator,
// which drifts enough over days to slide the standby schedule off its edges.
// 0 = never synced this boot (sentinel — millis() is already non-zero here, so
// a plain elapsed-time test would suppress the very first sync).
static uint32_t    s_last_ntp_sync_ms = 0;
static const uint32_t NTP_RESYNC_INTERVAL_MS = 3600000UL;   // 1 h

static void wifi_begin() {
    WiFi.disconnect(false);
    delay(100);
    WiFi.begin(s_wifi_ssid, s_wifi_pass);   // DHCP -- no static IP for this board
}

static void wifi_ota_init() {
    s_wifi_ssid = wifi_config_ssid();
    s_wifi_pass = wifi_config_pass();
    WiFi.mode(WIFI_STA);
    WiFi.setAutoReconnect(false);  // we drive retries manually via wifi_tick()
    wifi_begin();
    Serial.printf("Connecting to %s", s_wifi_ssid);

    uint32_t t = millis();
    while (WiFi.status() != WL_CONNECTED && millis() - t < 10000) {
        delay(250);
        Serial.print('.');
    }
    Serial.println();

    if (WiFi.status() == WL_CONNECTED) {
        Serial.printf("WiFi OK — IP: %s\n", WiFi.localIP().toString().c_str());
        // NTP is not started here — wifi_tick() owns the single sync path, so
        // a connect that lands after this 10s window still gets a clock.
    } else {
        Serial.println("WiFi slow — retrying every 20s via wifi_tick()");
    }

    xTaskCreate(ota_task, "OTA", 8192, NULL, 2, NULL);
}

// Declared extern in ui.cpp (status line shows retry count while disconnected).
uint32_t wifi_retry_count() { return s_wifi_retries; }

// Called from loop() — retries WiFi every 20 s when not connected.
// setAutoReconnect is unreliable in practice; retries are driven manually here.
static void wifi_tick() {
    static uint32_t last_retry = 0;
    if (WiFi.status() == WL_CONNECTED) {
        last_retry = 0;  // reset so we retry quickly after any future disconnect

        // Sync the clock the first time we ever see WiFi up this boot, then
        // re-sync hourly to bound RC-oscillator drift. Local time = UTC +
        // settings offset (settings-menu "Timezone" item); no DST handling.
        bool first_sync = (s_last_ntp_sync_ms == 0);
        if (first_sync || millis() - s_last_ntp_sync_ms >= NTP_RESYNC_INTERVAL_MS) {
            s_last_ntp_sync_ms = millis();
            configTime(settings.tz_offset_min * 60L, 0, "pool.ntp.org", "time.nist.gov");
            wlogf("[ntp] %s (tz offset %d min)\n",
                  first_sync ? "first sync" : "periodic resync",
                  (int)settings.tz_offset_min);
        }
        return;
    }
    if (millis() - last_retry < 20000) return;
    last_retry = millis();
    s_wifi_retries++;
    wlogf("[wifi] not connected (status=%d) — retry #%lu\n", (int)WiFi.status(), s_wifi_retries);
    wifi_begin();
}

void setup() {
    Serial.begin(115200);
    // Never block on USB CDC writes: with no host draining the port, the
    // default tx timeout stalls loop() for seconds per burst of log prints,
    // freezing GICAR polling (shot timer jerky / brew stop missed). Drop
    // output instead — confirmed via HA history 2026-07-03: machine_online
    // flapped 4s-on/10s-off whenever no serial monitor was attached.
    Serial.setTxTimeoutMs(0);
    delay(100);

    // Panel init + lv_init() + LVGL display-driver registration. Must run before
    // ui_init(), which requires lv_disp_drv_register() to have completed.
    display_init();

    // Load NVS credentials/settings before WiFi/UI need them.
    wifi_config_init();
    settings_init();

    // Build the UI widget tree on the registered LVGL display.
    ui_init();
    lv_timer_handler();   // first render before WiFi blocks (~10s connect timeout)

    // Register the GT911 touch pointer indev. Must come after ui_init()/the
    // first lv_timer_handler() -- see the comment on touch_init() in touch.cpp.
    touch_init();

    // WiFi connects first -- BLE scanning starts only after WiFi is up, per the
    // reference bring-up's note about WiFi/BLE coexistence contention on this
    // chip's shared 2.4GHz radio (both stacks run concurrently once both are
    // live; watch for this during Phase 6 testing).
    wifi_ota_init();
    scale_init();
    mqtt_init();

    // Bring up the GICAR link via the machine layer (gicar_init() plus the
    // MachineState reset -- calling gicar_init() directly here would leave
    // `machine` never populated, since only machine_update() reads gicar's
    // parsed frames into it). Blocks ~3 s during the boot handshake / config
    // read before returning; its diagnostics route to Serial via the wlog shim.
    // Deliberately called LAST, after display/touch/UI/WiFi init: the
    // empirically-validated reference bring-up calls machine_init() dead last
    // in setup() too. ui.cpp already renders a sane placeholder ("--.-°C",
    // disconnected) before real data arrives, so this ordering costs nothing
    // functionally.
    machine_init();
    shot_log_init();
}

void loop() {
    // Heartbeat: printed on a ~2 s cadence (not one-shot) so a passive serial
    // monitor attach can always catch it. Driven off millis() rather than a
    // blocking delay so LVGL keeps rendering smoothly between prints.
    static uint32_t last_heartbeat_ms = 0;
    if (millis() - last_heartbeat_ms >= 2000) {
        last_heartbeat_ms = millis();
        Serial.printf("Firmware build: %s (%s)\n", FW_GIT_HASH, FW_BUILD_TIME);
    }

    // Drain Serial1, pump the GICAR poll/parse state machine, and update the
    // `machine` struct ui.cpp reads (connected/coffee_temp_c/brew_active/...).
    machine_update();
    shot_log_update();
    flow_log_update();

    wifi_tick();
    mqtt_tick();
    ota_http_tick();   // service any MQTT-queued HTTP-pull OTA request
    wlog_tick();
    if (wifi_ap_active()) wifi_ap_handle();

    // Pump the UI (button events, screen transitions, label updates) and LVGL's
    // own timers/rendering. lv_timer_handler() must be called frequently for a
    // responsive display; LV_TICK_CUSTOM (lv_conf.h) sources time from millis().
    ui_tick();
    lv_timer_handler();

    delay(5);
}

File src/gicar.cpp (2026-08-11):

#include "gicar.h"
#include "wlog.h"
#include <driver/gpio.h>

// ─────────────────────────────────────────────────────────────────────────────
// La Marzocco Linea Mini — Gicar protocol driver
//
// Wire: GPIO2=TX, GPIO3=RX ↔ Gicar CN11, 9600 8N1, invert=true. (Moved off
// GPIO16/17 during Phase 5 bring-up -- see gicar.h for why.)
// CN11 signals are idle-LOW 2.5 V LVCMOS, so both lines must be inverted.
//
// Uses hardware UART1 (Serial1) with peripheral-level line inversion. An
// inherited claim said the C6 HP UART's inversion was broken (forcing a
// bit-banged EspSoftwareSerial fallback) -- but that claim was made while
// debugging on physically-defective pins and turned out to be wrong; see the
// note above _uart_setup(). Hardware UART also makes RX immune to the BLE
// scan's interrupt-timing corruption that broke bit-banged decoding.
//
// All frames are ASCII printable characters. Every command and every machine
// frame ends in a 2-char uppercase-hex checksum = (sum of the ASCII values of
// every preceding char) mod 256. Payload bytes inside R/Z frames are carried as
// hex pairs (two ASCII chars per byte).
//
// Four machine→ESP32 frame types are recognised by their first char:
//   'R'  poll response   — 81 chars, authoritative machine state (~760 ms)
//   'Z'  shot telemetry  — 55 chars, autonomous, only during brew/backflush
//   'X'  X-probe reply    — 11 chars, boot handshake only
//   'W'  write ACK       — 13 chars, follows a W command (see _parse_w_frame)
// ─────────────────────────────────────────────────────────────────────────────

// ── Framing constants ───────────────────────────────────────────────────────
static const int      R_FRAME_LEN   = GICAR_R_FRAME_LEN;  // 81
static const int      Z_FRAME_LEN   = GICAR_Z_FRAME_LEN;  // 54
static const int      X_FRAME_LEN   = 11;                 // "X00000001D9"
// Write ACK: 'w' + addr(4) + len(4) + "OK"(2) + cs(2) = 13 chars, e.g.
// "w00560001OK9D". Documented for the Gicar family in
// reference/lm_mini/gicar-serial/protocol.md; NOT yet confirmed on this
// machine, which is exactly why observing it is passive instrumentation only.
static const int      ACK_FRAME_LEN = 13;
// Config-block read response (0x0000/0x0020): "R" + addr(4) + len(4) +
// 2*32 hex + cs(2). Carries the machine's live setpoint at payload[7..8].
static const int      R_CFG_FRAME_LEN = 9 + 2 * 0x20 + 2; // 75
// 760 ms matches BOTH validated references (the WROOM build that worked
// end-to-end and the C6-era rewrite) and the factory gateway's own observed
// cadence in the sniffer captures. Our port briefly used 100 ms, which
// saturates the 9600-baud bus (~96% line utilisation) and collides with the
// machine's autonomous Z-frame stream during shots -- causing burst frame
// corruption, brew_active flapping, and the stuck/jumping shot timer.
static const uint32_t POLL_PERIOD_MS = 760;               // R-poll cadence
// Runtime-adjustable poll interval. The factory app slows polling to ~10 s
// during a backflush cycle (capture 07) — frequent polls abort the cycle at
// the first phase boundary.
static uint32_t _poll_period_ms = POLL_PERIOD_MS;
static const uint32_t RX_TIMEOUT_MS  = 200;               // stale-buffer reset

// Poll command: read 35 bytes (0x0023) from address 0x4000 — live machine state block.
// Address 0x0000 (config) returns all-zero payload for runtime state fields.
static const char POLL_CMD[] = "R40000023DB";

// ── RX accumulator state ─────────────────────────────────────────────────────
static char     _rxbuf[GICAR_BUF_SIZE];
static int      _rxlen      = 0;
static bool     _in_frame   = false;   // true once a frame-start char is seen
static int      _expect_len = 0;       // target length for the current frame
static uint32_t _last_rx_ms = 0;       // last byte arrival (for RX timeout)

static uint32_t _rx_total      = 0;
static uint32_t _last_poll_ms  = 0;
static int      _init_xb       = -1;   // bytes received during X-probe (-1=not run)
static int      _init_rb       = -1;   // bytes received during config read (-1=not run)

// ── Z-frame (shot telemetry) results ─────────────────────────────────────────
static uint8_t  _z_frame[GICAR_BUF_SIZE];
static int      _z_frame_len   = 0;
static bool     _z_ready       = false;
static bool     _z_shot_active = false;
static float    _z_temp        = 0.0f;
static uint32_t _frame_count   = 0;    // Z-frame counter (legacy name)

// ── R-frame (poll response) results ──────────────────────────────────────────
static bool     _r_ready         = false;
static float    _r_temp          = 0.0f;
static bool     _r_brew          = false;
static uint8_t  _r_boiler        = 0;
static float    _r_setpoint      = 0.0f;   // from boot config read
static uint32_t _r_frame_count   = 0;
static uint32_t _last_r_frame_ms = 0;

// ── Write-ACK results ────────────────────────────────────────────────────────
// First-wins latch: _ack_ready is only set when the previous ACK has been
// consumed. A standby burst writes five registers back-to-back (~68 ms at
// 9600 baud), so gicar_process() parses all five ACKs in a single drain pass —
// a last-wins slot would always end up holding the burst's LAST register and
// never the one the caller is looking for.
static bool     _ack_ready = false;
static uint16_t _ack_addr  = 0;
static bool     _ack_ok    = false;
static uint32_t _ack_ms    = 0;

// ── Handshake / boot state ───────────────────────────────────────────────────
static bool     _hs_ok = false;

// ─────────────────────────────────────────────────────────────────────────────
// Helpers
// ─────────────────────────────────────────────────────────────────────────────

// Checksum: sum of the ASCII values of the first `len` chars, mod 256.
static uint8_t _cs(const char* s, int len) {
    uint32_t sum = 0;
    for (int i = 0; i < len; i++) sum += (uint8_t)s[i];
    return (uint8_t)(sum & 0xFF);
}

// Decode one hex nibble; returns 0 for non-hex input (frames are validated by
// checksum, so a malformed nibble is caught upstream rather than here).
static uint8_t _nib(char c) {
    if (c >= '0' && c <= '9') return (uint8_t)(c - '0');
    if (c >= 'A' && c <= 'F') return (uint8_t)(c - 'A' + 10);
    if (c >= 'a' && c <= 'f') return (uint8_t)(c - 'a' + 10);
    return 0;
}

// Decode a hex byte pair (two ASCII chars) into a single byte.
static uint8_t _hex2(char hi, char lo) {
    return (uint8_t)((_nib(hi) << 4) | _nib(lo));
}

// Append a 2-char uppercase-hex checksum over the first `n` chars of `cmd`,
// then return the new total length. `cmd` must have room for 2 more chars.
static int _append_cs(char* cmd, int n, int cap) {
    uint8_t cs = _cs(cmd, n);
    n += snprintf(cmd + n, (size_t)(cap - n), "%02X", cs);
    return n;
}
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

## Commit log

2026-07-01 Initialize LineaMini_C6 project: reference docs for Firebeetle 2 ESP32-C6 + DFR1092 port
    Curated hardware/protocol reference from the ESP32-WROOM predecessor (W:\LM_Mini.git)
    plus freshly fetched DFRobot wiki docs for the new target board (DFR1075) and display
    (DFR1092). No firmware source yet — this is prep for a from-scratch port.
    Key correction found during research: the predecessor's assumed ILI9488 display driver
    is wrong for the DFR1092 — confirmed driver is ST7365P (Sitronix) via DFRobot's own
    linked datasheet and DFRobot_GDL library.
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2026-07-01 Firmware Phases 0-2: build scaffold, GICAR link, display bring-up
    Phase 0: PlatformIO scaffold for the Firebeetle 2 ESP32-C6, build-fingerprint
    heartbeat (tools/gen_build_info.py), native USB-CDC console.
    Phase 1: GICAR machine-interface UART on GPIO16(TX)/GPIO17(RX), adapted from
    W:\LM_Mini.git with EspSoftwareSerial instead of hardware Serial1 -- the C6's
    HP UART invert() is broken, so a hardware-UART port would silently fail
    against the real machine. Also carries corrected Z-frame parsing (54-byte
    frames, 32-bit temp decode), 100ms poll cadence, and periodic diagnostics --
    all sourced from previously-uncommitted, empirically-validated bring-up work
    found in an old working directory, not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
    [display.cpp, gicar.cpp, main.cpp]
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2026-07-01 Phase 4: GT911 touch bring-up, confirmed correctly aligned on hardware
    Adds src/touch.h/.cpp: a minimal direct-over-Wire GT911 driver (no external
    lib) registered as an LVGL LV_INDEV_TYPE_POINTER device, wiring up the
    previously-dead LV_EVENT_CLICKED callbacks in ui.cpp (main/timer/settings
    click handlers had no indev to fire from since Phase 3). I2C address is
    probed (0x5D then 0x14) since this DFR1092 SKU's touch chip was never
    factory-confirmed. Coordinate transform (native 320x480 portrait -> LVGL's
    480x320 logical space post setRotation(5)) derived from LovyanGFX's
    convertRawXY() rotation-5 bit math (pure transpose, no mirror) -- confirmed
    correct by the user tapping the real touchscree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
    [main.cpp, touch.cpp]
2026-07-02 Phase 5: fix GICAR live communication with real machine
    Wire the real GICAR machine-interface UART driver through the machine.h
    layer (main.cpp was calling gicar_init()/gicar_process() directly, which
    never populated the MachineState struct ui.cpp reads), and move the
    driver off GPIO16/17 to GPIO2/GPIO3 after GPIO16/17 produced zero bytes
    ever received despite wiring, continuity, and loopback all checking out
    (isolated to a physical defect at that header location on this board, not
    a protocol/software issue). Confirmed against the live machine: 100+
    R-frames parsing cleanly per test, live temp/boiler-flag data rendering
    correctly on the display.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
    [gicar.cpp, main.cpp]
2026-07-02 Fix Z-frame parsing and shot timer display
    gicar.cpp's Z-frame parser used an unconfirmed frame length (54 bytes,
    one short of the real 55-byte frame) and an unconfirmed temperature
    formula, both corrected against real reference captures
    (reference/lm_mini/gicar_protocol_analysis.md). The frame-length bug
    was desyncing frame boundaries during the ~11Hz autonomous Z-frame
    stream, causing brew-active detection to flap and the on-screen shot
    timer to lag/reset during a live shot.
    Also freeze the displayed shot time at its final duration once brewing
    stops (ui.cpp), instead of continuing to count up through the 3s grace
    period before the screen returns to Main.
    Confirmed against two live shots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
    [gicar.cpp]
2026-07-02 Phase 6 WIP: WiFi/OTA/MQTT/BLE scale/shot log + GICAR hardware UART
    Ports from LM_Mini reference: scale (NimBLE 2.x, Felicita Arc + Bookoo
    Themis), mqtt (PubSubClient, HA discovery, verified live incl. standby
    round-trip via Home Assistant), wifi_ap/wifi_config, wlog (telnet 4444),
    new shot_log (LittleFS, verified persisting across reboot). main.cpp
    rewired for full Phase 6 bring-up (WiFi DHCP, OTA task, NTP).
    GICAR driver changes:
    - Moved from EspSoftwareSerial to hardware UART1 with peripheral
    inversion (Serial1.begin(..., true)) -- works fine on the C6; the
    inherited "broken C6 inversion" claim was a misdiagnosis made on
    physically-defective GPIO16/17. HW FIFO makes RX immune to BL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
    [gicar.cpp, main.cpp, scale.cpp]
2026-07-02 Remove temporary loop-stall profiler -- shot defect confirmed fixed
    Live shot test (12 s) on real machine: shot START/END detected on the
    correct poll cycles, temp parsed continuously through the ~660 B/s
    Z-frame stream, zero loop iterations over 250 ms, user confirmed the
    display tracked correctly (temp live, timer prompt/running/stopping).
    Root cause was the 256-byte UART RX buffer + 100 ms poll cadence, both
    fixed in the previous commit.
    [main.cpp]
2026-07-03 Fix loop() stalls from blocking log writes -- real shot-timer root cause
    The morning-shot defect (jerky timer, brew stop missed) was NOT fully
    fixed by the UART RX buffer + poll cadence change: Serial.printf to the
    USB-Serial-JTAG CDC blocks when no host drains the port, stalling loop()
    ~10s out of every 14s and freezing GICAR polling. Every monitored test
    shot passed because the attached monitor drained the port -- HA history
    showed machine_online flapping 4s-on/10s-off for hours except exactly
    during capture windows.
    - Serial.setTxTimeoutMs(0): drop console output instead of blocking.
    - wlogf(): zero-timeout select() writability check before the TCP client
    write; NetworkClient::write bl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
    [main.cpp]
2026-07-03 Fix BLE scale never connecting -- three NimBLE 2.x API misuses
    The scale code was written against NimBLE 1.x semantics; on 2.x none of
    the discovery/connect path ever worked:
    1. NimBLEScan::start(10) is 10 MILLISECONDS in 2.x (seconds in 1.x) --
    every scan was 10 ms long and found nothing. Now start(10000).
    2. start() is non-blocking in 2.x; the code checked s_found immediately
    after, so even a successful find was wiped by the next loop pass and
    the connect path never executed. Now polls s_found for the scan
    duration.
    3. NimBLEClient::setConnectTimeout(5) is 5 ms in 2.x -- every connect
    attempt timed out instantly. Now 5000 ms.
    Also required: active scan (Bookoo advertises i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
    [scale.cpp]
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2026-07-03 v0.16 UI rework: edge adjusters, CLEAN on Main, bold type, auto-offset
    Main screen:
    - Bold 72px custom font (Montserrat wght=700 via fontTools instancer;
    glyphs: space digits . - degree C g s) for the actual temp, now centred
    top. Replaces the regular-weight font; touch coordinates fixed earlier
    (GT911 point block starts at 0x814F not 0x8150) make all the new
    positional buttons usable.
    - Set-temp adjuster column flush left (0.5 deg steps, 88-96): commits to
    NVS and sends machine_set_temp() once, 3 s after the last tap.
    - Target-weight adjuster column flush right (1 g steps, 20-60 g).
    - CLEAN moved from Settings to a hold-2s pill (amber while held); firing
    arms machine_trigger_cle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
    [touch.cpp]
2026-07-03 Working cleaning cycle: GICAR choreography + guided countdown UI
    Protocol (machine.cpp/gicar.cpp) -- reverse-engineered against capture 07
    and four live failures; the sequence the machine actually requires:
    1. Burst of exactly 6x W00E1=0x82 at 1 s intervals, lever DOWN.
    - A single pulse never engages the cycle (old one-shot
    machine_trigger_clean never worked from Settings/MQTT/UI).
    - Pulses landing after the cycle starts ABORT it after one pump
    phase -- so remaining pulses are dropped if the lever comes up
    early, and the UI only invites the lever after the burst.
    2. Near-silence during the cycle: R-polls slowed to 10 s
    (gicar_set_poll_period), no further pulses -- mat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
    [gicar.cpp]
2026-07-04 v0.17: OTA updates working + status line replaced by connectivity dot
    - Root cause of OTA failure: huge_app.csv has no ota_0/ota_1 pair, so
    ArduinoOTA answered the espota invitation but Update.begin() failed
    silently. New partitions_lm_ota.csv: two 1.98MB OTA slots + 64KB
    LittleFS (app is 92.3% of a slot).
    - Main screen: IP/MQTT/RSSI status text and GICAR debug counters
    removed. A 16px dot (green = WiFi+MQTT up) plus the FW version now
    sit bottom-left; the dot is always visible.
    - Verified live: serial flash laid down the new table, then two
    successive espota uploads from Windows applied and booted.
    [partitions_lm_ota.csv]
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2026-07-04 v0.20: HEAT indicator, MENU long-press box, slimmer settings menu
    - Main screen: HEAT pill top-left (mirrors STEAM top-right), lit red while
    the machine reports the boiler heating element on (boiler_flags bit 0).
    - Settings access: long-press on a visible MENU box (bottom-centre)
    replaces tap-anywhere-on-screen; plain taps on the background do nothing.
    - Settings menu: Coffee temp entry removed (adjusted from the main screen
    edge arrows since v0.16; CLEAN was already removed).
    - gicar: cfg[7..8] confirmed live as the machine's EFFECTIVE setpoint —
    it soft-start ramps during warm-up (85->91->93) then parks at the true
    target; comment corrected, full 32-byte cfg-block dump kept for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
    [gicar.cpp]
2026-07-04 v0.21: standby schedule + timezone setting + tap-to-wake overlay
    - Schedule screen (Settings > Schedule): daily wake/sleep times, hour and
    15-min arrows in the main screen's edge-column idiom, ENABLED toggle,
    next-event countdown, clock/NTP footer. Times persist to NVS.
    - Scheduler: edge-triggered once per minute in ui_tick(); sleep skipped
    while brewing/cleaning and retried up to 15 min; manual wake between
    edges is never fought; inert until first NTP sync.
    - Sleeping overlay on the main screen while machine.standby: SLEEPING +
    wake time, tap anywhere wakes (manual override).
    - Timezone: settings-menu item (UTC offset, 30-min steps, default +02:00);
    applied to SNTP at boot and i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
    [main.cpp]
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2026-07-06 S3 port Phase 1: per-env DEVICE_HOSTNAME (linea-mini-s3)
    Distinct mDNS/OTA hostname so C6 (in machine) and S3 (on bench) can
    coexist on the network. Bring-up verified on hardware: workbench flash,
    boot heartbeat, WiFi join, wlog :4444, OTA round-trip on the 16MB
    partition table (tools/ota_upload.py, rx-counter reset confirmed).
    [main.cpp]
2026-07-06 S3 port Phase 2: fix touch I2C wedge (init after ui_init, not before)
    On the DFR0975, calling touch_init() before ui_init()/the first
    lv_timer_handler() left the ESP32-S3 I2C peripheral wedged -- every
    GT911 transaction short-read from loop() onward, even though the
    chip ACKed fine during setup(). Moving touch_init() to run after the
    display/LVGL bring-up sidesteps it. Verified against real hardware:
    GT911 found at boot, 330+ touch points captured during a live tap
    test, config register readback correct (xmax=320 ymax=480).
    C6 build unaffected (never showed the symptom; still builds clean).
    [main.cpp, touch.cpp]
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2026-07-07 WIP: S3 GICAR pin hunt continues -- try RX=44/TX=14, display FPC broken
    GPIO10/11 (A4/A5) ruled out: live bring-up produced zero received
    bytes despite wire continuity, GND continuity, and a clean blink test
    on both pins. GPIO43 (default UART0 TX) also ruled out: bare-pin
    blink test only reached 0.75V under drive, indicating real hardware
    loading on this specific board.
    Current attempt: RX=GPIO44 (bare-blink-tested clean 0-3.3V swing),
    TX=GPIO14 (proven during the earlier GPIO13/14 silk-trap episode --
    carried real 125 B/s GICAR traffic; the only fault there was RX=13
    sharing the touch-INT trace). GICAR_WIRE_TEST flag + main.cpp blink
    block let a DMM confirm the physical pads before solderi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
    [gicar.cpp, main.cpp]
2026-07-08 S3 display hand-wired + touch working; remove GICAR wire-test and temp diagnostics
    Display FPC replaced by point-to-point wiring (TFT_RST initially landed on
    GPIO12/TOUCH_RST -- moved to GPIO38; TP_R now on GPIO12). GT911 confirmed
    alive at 0x5D and reporting touch points.
    Touch 'not working' turned out to be loop() starvation, not hardware: the
    TEMP rawpin diagnostic in gicar.cpp blocked ~4s of every 5s while no R-frames
    arrived (machine disconnected), so LVGL barely polled the GT911. Removed it,
    plus the GICAR_WIRE_TEST boot blink (GPIO44 confirmed by DMM) and the temp
    touch status logging. Touch verified responsive on the cleaned build.
    GICAR live test on RX=44/TX=14 still pending -- CN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
    [gicar.cpp, main.cpp]
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2026-07-08 CAD: replacement COVER GROUP LMR (C.1.743) with DFR1092 display pod
    Parametric OpenSCAD model from caliper measurements of the stock part
    (300x130x3, r4 corners, four 5mm holes at 18/10mm insets, no flanges).
    Display pod on the right: screen at 70deg from horizontal, yawed 10deg
    inward for cup-tray access. DFR1092 mounts from behind the face skin on
    M2 bosses; cable chimney through the wedge to a panel slot; S3 standoff
    through-holes left of the pod. For ABS/ASA print.
    [cover_group.scad, cover_group.stl]
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2026-07-08 CAD: open-back display housing, yaw corrected inward, 2mm corner fillets
    Pod restructured from a sealed hull-wedge to an open-backed frame housing:
    DFR1092 slides in from the back onto the M2 bosses with straight-on
    screwdriver access, harness drops through a panel slot under the opening.
    Supported by triangular side cheeks + front apron closing the under-lip
    gap. Yaw sign flipped so the face turns 10deg INWARD (toward the operator);
    housing outline corners carry a 2mm fillet.
    [cover_group.scad, cover_group.stl]
2026-07-08 CAD: manifold fix -- overlap apron/cheeks into housing volume
    [cover_group.scad, cover_group.stl]
2026-07-08 CAD: snap-in back cover carrying the FireBeetle; drop panel S3 holes
    Back cover (second STL, cover_group_back.stl): plate with 2mm-radius
    corners, harness notch, two flexing snap tabs (1.6mm fingers, 0.8mm ramped
    nubs into wall slots at nub_z=9.5), and four M2 bosses on its inner face
    at the DFR0975's 22x51.4 hole grid -- the S3 mounts on the cover, making
    the pod a self-contained controller. Housing deepened (wire_space 15) for
    the board stack. Panel S3 standoff holes removed per user. render_part
    selector: all / main / back_cover.
    [cover_group.3mf, cover_group.scad, cover_group.stl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]
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2026-07-08 Shot counters (total + since-clean) + OTA BLE scan-hold; NOT yet deployed
    Shots-since-clean counter: new settings.shots_since_clean (NVS key
    shots_cln), incremented with shot_count at brew start, reset to 0 on both
    clean-start paths (UI hold-pill and HA MQTT command; reset deliberately
    outside the NTP sanity gate -- only the epoch needs valid time). Main
    screen shows 'N shots / M since clean'; new HA sensor 'Shots since clean'
    in discovery + state JSON.
    OTA fix (untested): scale_set_ota_hold() stops BLE scanning for the
    duration of an OTA transfer -- live capture showed the transfer stalling
    mid-stream exactly while '[scale] scanning' ran on the shared radio.
    ArduinoOTA.onStart sets the hol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
    [main.cpp, scale.cpp]
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2026-07-09 v0.24: reliable OTA — MQTT-triggered HTTP-pull + hardened espota
    Root causes fixed:
    - BLE/WiFi coex: scale_radio_release() fully deinits NimBLE (scan-pause
    is not enough — the controller keeps time-slicing the radio), then
    WiFi.setSleep(false) becomes legal for the transfer window.
    - ArduinoOTA wedge (arduino-esp32 #8393): onError now Update.abort()
    + ESP.restart() so every attempt starts clean.
    - New pull path: lm_mini/cmd/ota (URL payload, or PRESS -> default
    build-PC URL) -> ota_http.cpp downloads via HTTPUpdate (outbound TCP,
    no host firewall in path) and reboots. HA 'Update firmware' button
    added (12 discovery entities).
    - mqtt on_msg val[32] -> val[160]: 32 truncated UR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
    [main.cpp, scale.cpp]
2026-07-09 v0.25: GitHub-release OTA — on-device update check, CI release pipeline
    - Settings menu 'Firmware update': checks this repo's latest GitHub
    release (version.json via TLS, redirect-following) and installs
    firmware.bin on a second tap. S3-only (-DFEATURE_GH_OTA); the C6 env
    stays off (TLS pushes its 4MB partition to 99%).
    - MQTT broker config moved to NVS (ns 'mqttcfg', wifi_config pattern):
    seeded once from a locally-built secrets.h, so CI-built binaries
    (blank secrets stub) keep the broker connection after updating.
    - FW_VERSION moved to include/version.h (shared by ui + ota modules).
    - Loop task stack 8K -> 20K: the TLS install path runs on it.
    - .github/workflows/release.yml: t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
    [main.cpp]
2026-07-09 v0.26: fix GitHub OTA check (TLS out of internal RAM) + CI-build credential seeding
    - LVGL heap to PSRAM on the S3 (LV_MEM_CUSTOM/ps_malloc): the 48KB
    static pool plus the loop-stack bump left ~32KB internal free and
    mbedtls failed with 'SSL - Memory allocation failed' on every GitHub
    check. C6 (no PSRAM) keeps the static pool.
    - OTA transfer moved off the loop task into a dedicated 16KB task;
    loop stack back to default (frees 12KB internal permanently).
    - wifi_config now seeds NVS once from a non-empty compiled-in SSID,
    same rule as mqtt_config — CI-built images (blank secrets stub)
    inherit working WiFi credentials.
    - Check-path diagnostics (heap/RSSI/TLS lastError) kept: one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
    [main.cpp]
2026-07-09 v0.27: fix GitHub install hang — manual streamed download + confirm/progress UI
    - httpUpdate.update() hung silently 90+s against GitHub (field-captured
    via wlog); replaced with a manual HTTPClient streamed download using
    the exact client config the working check path proved (setInsecure,
    30s handshake, 20s connect/read, strict redirect follow), writing
    4KB chunks to Update with a 20s stall abort. Every exit reboots.
    - Re-entrancy guard: repeated install taps spawned duplicate transfer
    tasks ('failed to spawn' spam); now refused while one runs.
    - LVGL thread-safety: ui_ota_start() moved to loop context; the
    transfer task publishes only a volatile percent, and the main screen
    p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
    [main.cpp]
2026-07-09 v0.29: GitHub check frees the radio — BLE suspend/resume around the TLS fetch
    The precompiled core pins mbedtls to internal RAM
    (CONFIG_MBEDTLS_INTERNAL_MEM_ALLOC); with the scale CONNECTED only
    ~45KB internal is free and every check died with 'SSL - Memory
    allocation failed'. The check now suspends BLE (park + deinit, ~50-90KB
    freed), fetches, then resumes: scale_ble_setup() factored out so
    NimBLE re-inits cleanly and the parked scan task picks up a fresh scan
    handle. Install path unchanged (suspend + reboot). Both OTA actions now
    refuse while a brew is active — suspending the scale mid-shot would
    break brew-by-weight.
    [scale.cpp]
2026-07-09 CAD v2: 20-deg front-facing pod, install-from-below, snap bottom cover
    - Mount holes 9.5mm in from L/R edges (+0.5mm gap per side vs fit test)
    - Display 20 deg from horizontal, facing front, no yaw
    - Housing +10mm each side of the module for cable slack (122mm face)
    - Sealed pod: no rear hatch; only opening faces down through a
    110x46mm installation aperture in the panel (display posts in at an
    angle, screws up onto the face bosses)
    - New snap-in bottom cover (4 tabs onto the panel edge) with an open
    25mm cable notch on its rear edge; cover_group_back.stl retired
    - FireBeetle bosses removed (clashed with display screws; fixing TBD)
    STLs re-exported, all manifold: cover_group.stl,
    cove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
    [cover_group.scad, cover_group.stl, cover_group_back.stl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]
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2026-07-14 v0.31: fix bbw stop standby side effects, responsiveness, standby button
    The 0x8000 pump-cut is rejected by the GICAR (test-mode-only register), so the
    standby toggle is now the immediate stop, with a second wake after the lever
    returns to Stop — the machine queues the mid-brew standby until then, which
    was dropping it into standby, killing group reheat, and deadening the next
    pull. Also: 1 s MQTT socket timeout + no publishes mid-shot (UI freezes),
    scale-loss failsafe stop, screen returns on the lever edge, deferred shot-log
    write, manual-only pre-stop offset (learner removed), standby button on the
    main screen, 15 s scan cadence parked during machine standby, retained OTA
    trigger, lever-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
    [scale.cpp]
2026-07-15 v0.32-v0.37: standby confirm, main-screen rework, BLE/WiFi coex fixes
    Standby button now needs a 2s hold + yes/no confirm. Main screen reworked:
    temp centered, larger scale weight, clean counter above MENU, tappable SCALE
    connect pill top-right, HEAT/STEAM pills replaced by status dots top-left.
    Scale BT on/off setting; idle scan pause 15s->60s (10s scans at 15s pause
    degraded WiFi within minutes). OTA tools: paced sends so "served" reflects
    real device consumption on a slow link; espota callback moved to port 8070.
    [scale.cpp]
2026-07-28 v0.38-v0.40: settable pre-stop offset via HA, clock re-sync + wake window, bbw 2nd-shot tare gate
    - HA "Pre-stop offset" is now a number entity (cmd/prestop) instead of a
    read-only sensor, so the auto-tune automation can write it back; new Scale
    Weight / Scale Connected / Brew Target sensors (16 discovery entities).
    MQTT buffer bumped 512->768 to cover the larger state payload (PubSubClient
    silently drops oversized publishes rather than truncating).
    - NTP is now (re)synced from wifi_tick()'s connected branch instead of once at
    boot: a missed boot-time WiFi window previously left the clock permanently
    unset, and long uptimes drifted with no re-sync. Wake now uses the same
    15-min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
    [main.cpp]
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2026-09-24 Show live scale status on the SCALE pill (v0.50)
    The SCALE pill forced a reconnect on tap but gave no visible response, and
    "connected" vs "searching" could not be told apart because only
    scale.connected was exposed. The user could not tell whether a tap had
    registered.
    scale.cpp now publishes a display-only ScaleLink phase (OFF, PAUSED, IDLE,
    SCANNING, CONNECTING, CONNECTED), written only by the scale BLE task. The
    pill shows one state at a time: green SCALE when connected, grey SCALE when
    idle, blinking amber SEARCHING after a tap, red NO SCALE for 4 s when a
    search fails (or after a 20 s cap), and dim BT OFF when the radio is off.
    Only tap-initiated searches show SEARCHING, so a machine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
    [scale.cpp]
2026-09-26 Clear the Bookoo scale clock automatically at every lever return (v0.54)
    The user had to reset the scale by hand before each shot, and a group-head
    flush started the scale clock again. The cause was in our firmware: every
    brew start sent Bookoo tare+start (0x07), flush included, and nothing ever
    sent stop (0x05) or reset (0x06).
    New behaviour: at brew start, RESET the clock if it is non-zero, then
    TARE_AND_START. When the lever returns to Stop, send STOP at once (holding
    the shot time on the scale) and a forced RESET 2 s later (SCALE_RESET_DELAY_MS).
    The reset must bypass the timer_ms != 0 guard, because STOP alone leaves the
    clock non-zero only briefly and a guarded reset would be a silent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
    [scale.cpp]
